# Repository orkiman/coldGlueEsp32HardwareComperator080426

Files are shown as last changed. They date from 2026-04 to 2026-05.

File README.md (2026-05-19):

# Cold Glue Controller — Main Controller Firmware (Stage 1)

ESP32-S3-WROOM-1-N16R8 firmware for a 4-channel high-speed cold-glue gun
controller. Up to 330 Hz droplet rate; current chopping is handled by the
on-board LM339 hardware loop. The ESP32 only orchestrates phase transitions.

See `docs/initial prompt.md` for the full hardware architecture and operational
spec.

## Toolchain

PlatformIO (recommended). Open the project folder in VS Code with the
PlatformIO extension and use `PlatformIO: Upload` / `Monitor`.

```
pio run -t upload
pio device monitor
```

## Source Tree

```
src/
  main.cpp                          task wiring + boot order
  config/Config.{h,cpp}             double-buffered config + pattern storage
  comms/
    Events.{h,cpp}                  Core1->Core0 lock-free event queue
    UartJson.{h,cpp}                NDJSON parser + command dispatcher
  hw/
    Pins.h                          pin map (verbatim from docs)
    Driver.{h,cpp}                  IN1/IN2/MUX_SELECT abstraction, killAll
    Dac.{h,cpp}                     MCP4728 with task-serialized I2C writes
    Encoder.{h,cpp}                 PCNT counter + photocell ISR (any-edge)
  rt/
    GunSequencer.{h,cpp}            per-gun Peak/Hold/Decay state machine
    PatternScheduler.{h,cpp}        sheet FIFO + lazy pattern walker
    Control.{h,cpp}                 surface called by JSON dispatcher
  sys/
    Fault.{h,cpp}                   nFAULT ISR -> master kill
    Watchdog.{h,cpp}                HMI link timeout
    Status.{h,cpp}                  5 Hz status emitter
```

## Task Layout

| Core | Task | Prio | Purpose |
| ---- | --- | ---- | --- |
| 0 | `uart_rx` | 4 | NDJSON parser |
| 0 | `evt_emit`  | 5 | Drains event queue to Serial |
| 0 | `wdog` | 3 | HMI link watchdog |
| 0 | `status` | 2 | 5 Hz `{"event":"status"}` |
| 1 | `pattern` | 7 | Encoder poll + fire pattern events |
| 1 | `dac` | 6 | Coalesced MCP4728 I2C writes |
| 1 | ISRs | IRAM | Peak (x4), photocell, nFAULT, PCNT |

## Protocol

Newline-delimited JSON over UART0 (115200 8N1) on GPIO 43 TX / GPIO 44 RX,
routed through the on-board CP2102 USB-UART for development.

Commands and events follow `docs/initial prompt.md` Section 8 exactly.

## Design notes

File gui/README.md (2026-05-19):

# Cold Glue Controller — PC GUI

Operator interface for the ESP32-S3 cold glue controller. Talks NDJSON
over USB serial (CP2102 @ 115200) to the firmware in `../src/`.

## Stack

- Python 3.11+
- PySide6 (Qt 6) — RTL Hebrew UI, QGraphicsView pattern editor
- pyserial — serial transport

## Install

```powershell
python -m venv .venv
.\.venv\Scripts\Activate.ps1
pip install -r requirements.txt
```

## Run

```powershell
python run.py            # real serial
python run.py --mock     # in-process fake firmware, no hardware needed
```

## Packaging (later)

```powershell
pyinstaller --noconsole --onefile run.py -n GlueController
```

## Layout

```
gui/
  run.py                       entry point
  app/
    protocol.py                NDJSON command builders + event parsing
    link_base.py               abstract link (Qt signals)
    serial_link.py             pyserial implementation
    mock_link.py               in-process fake firmware
    state.py                   central app state (config, patterns, status)
    profiles.py                save/load profile JSONs
  ui/
    theme.py                   palette + QSS loader
    styles.qss                 dark industrial theme
    main_window.py             shell with sidebar nav
    widgets/
      connection_bar.py        COM picker + status LED + ping
      numeric_field.py         labelled spinbox with units
      pattern_editor.py        QGraphicsView pattern canvas (TBD)
    screens/
      operate.py               start/stop, live status
      patterns.py              visual pattern editor host
      configure.py             per-gun currents + hold time
      admin.py                 calibration, globals, event log
```

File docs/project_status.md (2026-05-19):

# Cold Glue Controller — Project Status

> Living document. Reflects what is **actually implemented** in firmware.
> The original spec lives in `initial prompt.md` and should not be edited;
> this file records any decisions, deltas, and the current state.

Last updated: Stage 2 GUI scaffold (PySide6) in progress; per-gun
`on_timeout_ms` (renamed from `hold_time_ms`, semantics changed to
"start-of-cycle timer") landed in both firmware and GUI.

---

## 1. Stage Status

| Stage | Scope | Status |
| ----- | --- | --- |
| 1 | ESP32-S3 main controller firmware | **Code complete** — pending hardware bring-up |
| 2 | PC-side GUI over UART0 (PySide6) | **In progress** — `gui/` tree; mock-link works, real-link path implemented |

The original Stage 2 plan was an LVGL HMI on a second ESP32-S3 + 7" touch
panel. **Revised decision:** for now the operator UI runs on a PC and talks
to the main controller through the on-board CP2102 USB-UART. The wire
protocol (NDJSON over UART0 @ 115200) is identical, so swapping back to an
embedded HMI later is a drop-in.

---

## 2. Implemented Architecture

### Dual-core task layout

| Core | Task | Prio | File | Purpose |
| ---- | --- | ---- | --- | --- |
| 0 | `uart_rx` | 4 | `comms/UartJson.cpp` | NDJSON parser + command dispatcher |
| 0 | `evt_emit`  | 5 | `comms/Events.cpp` | Drains lock-free event queue -> Serial |
| 0 | `wdog` | 3 | `sys/Watchdog.cpp` | HMI link timeout (2 s) |
| 0 | `status` | 2 | `sys/Status.cpp` | 5 Hz `{"event":"status"}` |
| 1 | `pattern` | 7 | `rt/PatternScheduler.cpp` | Encoder poll + fire pattern events |
| 1 | `dac` | 6 | `hw/Dac.cpp` | Coalesced MCP4728 I2C writes |
| 1 | ISRs | IRAM | `hw/Encoder`, `rt/GunSequencer`, `sys/Fault` | Peak (x4), photocell, nFAULT, PCNT overflow |

### Key isolation rules (enforced by file layout)

- Only `evt_emit` task ever touches `Serial`. No other module may print.
- ISRs never block on I2C: DAC writes are queued to the Core-1 `dac` task.
- Config is published via atomic double-buffer pointer swap; hot path reads
  are lock-free.
- Cross-core events use FreeRTOS queues with `*FromISR` APIs.

---

## 3. Dot Sequence — Implementation Map

| Phase | Trigger | File / function |
| --- | --- | --- |
| 1 Peak / Pick | `seq::fire(g)` | `rt/GunSequencer.cpp :: fire()` |
| 2 Hold (chopping) | LM339 peak IRQ | `rt/GunSequencer.cpp :: peakIsr()` |
| 3 Active Fast Decay  | on-timer expiry OR `seq::abort()`| `rt/GunSequencer.cpp :: onTimerCb() / abort()` |

Per-gun state machine is `Idle -> Peak -> Hold -> Decay -> Idle`, guarded
by a `compare_exchange_strong` so `fire()` is safe from any context.

### On-timer (Peak+Hold budget)

`fire()` arms a single `esp_timer` (`onTimer`, per gun) for the full
per-gun `on_timeout_ms` budget, starting **at the moment of fire()**, not
at the LM339 peak trip.  This means:

- Normal flow: LM339 -> `peakIsr` -> Hold phase; the same timer keeps
  counting and forces Phase 3 when the budget expires.
- Fault flow: if the peak trip never arrives (open coil, broken sense,
  wrong threshold), the same timer still fires, drops the gun into
  Phase 3, and masks the late IRQ defensively.  No more "stuck in Peak"
  failure mode.
- `seq::abort(g)` stops the on-timer and force-enters Phase 3 (used by
  Lines to terminate at the encoder-position end of the line).

---

## 4. Pattern Execution

- Per-gun **sheet FIFO depth = 4** (`SHEET_QUEUE_DEPTH` in `PatternScheduler.cpp`).
- Sheet entries store only the encoder pulse count at the photocell leading
  edge. Patterns are walked **lazily** at runtime — dots are not pre-expanded.
- Pattern coordinate origin = paper leading edge =
  `photocell pulse + photocell_offset_mm * pulses_per_mm`.
- If gap between sheets < `photocell_offset_mm`, multiple sheets are tracked
  in flight on the same gun. Queue overflow drops the new trigger silently.
- Speed-safety: if measured speed drops below `min_speed_mm_s`, the pattern
  task suppresses firing until speed recovers.

---

## 5. Diagnostic `test_open` Behaviour (revised)

`test_open` no longer issues a single raw dot. Behaviour depends on the gun's
currently configured pattern type (see `rt/TestRunner.cpp`):

| Pattern type | Test behaviour |
| --- | --- |
| `lines` | Single line, hardware-regulated, held for `timeout_ms`, then Phase 3 |
| `dots` | Continuous dot train at 20 Hz until `timeout_ms` or `test_close` |
| `none` | `{"event":"error","cmd":"test_open","reason":"no_pattern_or_busy"}`  |

`gun:0` broadcasts the test to every gun with a configured pattern.
`timeout_ms` is capped at 5000 in `UartJson::handleTestOpen`.

---

## 6. Fault & Safety Path

- **nFAULT (GPIO 39, active LOW)**: IRAM ISR in `sys/Fault.cpp` immediately
  calls `drv::killAll()`, aborts all gun sequencers, sets
  `g_sys.fault = true`, `g_sys.active = false`, and emits
  `{"event":"error","reason":"hardware_fault"}`.
- Recovery requires a fresh `set_active:true` from the operator.
- **Watchdog**: any received NDJSON command (incl. `ping`) refreshes the
  timestamp. After 2 s of silence while active, outputs are killed and
  `{"event":"watchdog_timeout"}` is emitted.

---

## 7. Protocol — Deltas From `initial prompt.md` §8

### 7.1 New error reason

| Where | Reason | Meaning |
| --- | --- | --- |
| `test_open` | `no_pattern_or_busy` | Gun has no pattern, or a test is already running on it. |
| `set_pattern`  | `bad_on_timeout` | `on_timeout_ms` was supplied but ≤ 0. |

All other validation errors (`bad_pulses_per_mm`, `hold_ge_pick`, etc.) are
sanity checks in `set_config` / `set_pattern`.

### 7.2 `on_timeout_ms` — per-gun, start-of-cycle

Previously a global `hold_time_ms` in `RuntimeConfig` was started by
`peakIsr` and counted only the Hold phase.  It has been replaced by a
per-gun `on_timeout_ms` inside `GunPattern`, started by `fire()` itself
and counting the **entire** Peak+Hold budget.

- `set_config` **no longer accepts** any droplet-timing field.
- `set_pattern` accepts a top-level optional `on_timeout_ms` (ms, float).
  Absent → preserve previous per-gun value (`editScratch()` copies the
  active buffer).
- Default per-gun value at boot: **1.2 ms**.
- **Dots mode**: `on_timeout_ms` is the user-facing droplet on-time.
- **Lines mode**: `on_timeout_ms` is used only as a long safety ceiling
  (`seq::fire(g, 5000)` is hard-capped to 5 s inside `fire()`).  Line
  termination is encoder-position driven (`seq::abort(g)` at `end_mm`,
  see `PatternScheduler::patternTask`).  Speed-safety (`min_speed_mm_s`)
  still suppresses firing entirely.
- **No more "stuck in Peak"**: because the on-timer starts at `fire()`,
  a missing LM339 trip cannot pin IN1 HIGH indefinitely.

Example payload:

```json
{ "cmd": "set_pattern", "gun": 2, "type": "dots",
  "on_timeout_ms": 1.8,
  "elements": [ {"start": 60, "end": 240, "spacing": 5} ] }
```

---

## 8. Open Items For Bench Bring-Up

- **`Adafruit_MCP4728::fastWrite` signature** — assumed `(uint16_t, uint16_t, uint16_t, uint16_t)` returning `bool`; will fail at compile if the installed lib differs.
- **PCNT glitch filter** at 100 APB ticks (~1.25 µs). Will tune once we see the 6N137's real edge behaviour on the scope.
- **`NEAR_ZERO_V = 0.10 V`** Phase-3 termination threshold. Tunable in `rt/GunSequencer.cpp`. Right now corresponds to ~0.05 A coil current.
- **On-timer dispatch via `esp_timer` task context** (not ISR). Worst-case latency ~50 µs; fine for on-times ≥ 1 ms but introduces jitter if `on_timeout_ms` is set absurdly small.
- **No `error` event yet for the "peak trip never arrived" case** — the
  on-timer correctly drops the gun into Phase 3 (no stuck-in-Peak any
  more), but we still can't tell from outside whether a given fire cycle
  passed through `peakIsr` or hit the on-timeout without it.  *Future:*
  emit a diagnostic event from `onTimerCb` if the gun was still in
  `Phase::Peak` when the timer expired.

---

## 9. File Tree (current)

```
platformio.ini
README.md
docs/
  initial prompt.md            (immutable spec — do not edit)
  project_status.md            (this file)
src/                           (ESP32-S3 firmware)
  main.cpp
  config/Config.{h,cpp}
  comms/Events.{h,cpp}    UartJson.{h,cpp}
  hw/Pins.h               Driver.{h,cpp}   Dac.{h,cpp}   Encoder.{h,cpp}
  rt/Control.{h,cpp}      GunSequencer.{h,cpp}   PatternScheduler.{h,cpp}   TestRunner.{h,cpp}
  sys/Fault.{h,cpp}       Watchdog.{h,cpp}       Status.{h,cpp}
gui/                           (PySide6 operator UI)
  run.py                       Launcher (`--mock` for offline dev)
  requirements.txt
  app/
    protocol.py                NDJSON command builders + enums
    link_base.py               Abstract link (Qt signals)
    mock_link.py               In-process simulator
    serial_link.py             pyserial-backed real transport
    state.py                   AppState — single source of truth
    profiles.py                Save/load full operator profile (JSON)
  ui/
    main_window.py             Sidebar (הפעלה / תוכנית / הגדרות) + menu
    styles.qss                 Dark theme
    screens/operate.py         Run-time controls + live status
    screens/patterns.py        Per-gun toolbar + visual editor (4 lanes)
    screens/configure.py       Currents, globals, calibration, event log
    widgets/connection_bar.py  COM picker / Connect / Active / E-stop
    widgets/numeric_field.py   Debounced labelled spinbox
    widgets/pattern_editor.py  QGraphicsScene-based segment editor
```

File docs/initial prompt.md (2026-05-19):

**User Instruction:** Copy and paste this entire document into a new AI chat to instantly bring the AI up to speed on your project.

# System Prompt for AI: Cold Glue Gun Controller Firmware

Act as an expert Embedded C++ Firmware Engineer and Industrial Electronics Specialist. I am developing firmware for a custom "Cold Glue Controller" PCB used in high-speed industrial manufacturing (up to 330Hz droplet rate).
The hardware design is complete and validated. **Do not suggest altering the core hardware architecture.** Your job is to help me write, optimize, and debug the C++ firmware for the ESP32-S3 using the Arduino IDE / PlatformIO framework.

Please read the following hardware context and operational logic carefully before writing any code.

## 1. Project Context & Core Architecture

* **Microcontroller (Main Controller):** `YD-ESP32-S3` compatible board (specifically `ESP32-S3-WROOM-1-N16R8` with 16MB Flash, 8MB PSRAM). Strictly 3.3V logic.

* **Power Systems:** * **High Power:** 48VDC (for solenoids), with reverse polarity protection and bulk capacitors for absorbing regenerative currents.

  * **Logic Power:** 24VDC stepped down to 5V (via K7805 switching regulator), and then to 3.3V via the ESP32 internal regulator.

* **Outputs:** 4 independent high-speed cold glue guns (solenoids).

* **Control Method (Hybrid Hardware/Software):** To prevent the ESP32 from crashing due to high-frequency interrupt storms, the board uses a **hardware-assist handoff** (Hardware Sense Loop) to manage the solenoid current chopping (PWM). The ESP32 acts as the orchestrator.

## 2. Bill of Materials (Core Actuation Components)

* **Motor Drivers:** 2x `DRV8262` (One chip per 2 guns). Configured in independent PWM Mode (`MODE1` & `MODE2` = GND, `nSLEEP` = HIGH).

  * *Truth Table:* `IN1=1, IN2=0` (Forward); `IN1=1, IN2=1` (Slow Decay/Brake); `IN1=0, IN2=1` (Reverse); `IN1=0, IN2=0` (Coast/Fast Decay).

* **Current Sense:** 4x `INA240A2DR`. Fixed gain of 50 V/V, measuring across 40mΩ shunts.

  * *Formula:* Vout = I_amps * 0.04Ω * 50 = I_amps * 2 (e.g., 1.0A = 2.0V, 0.4A = 0.8V).

* **DAC:** 1x `MCP4728` (I2C, 3.3V). Sets the dynamic reference voltage (thresholds) for the comparators.

* **Hardware Comparators:** 1x `LM339` Quad Comparator (5V power, 10k pull-ups to 3.3V on outputs). Compares INA240 output against the DAC threshold.

* **Hardware MUX:** 4x `74LVC1G157` (3.3V). Routes signals to the DRV8262 `IN2` pin.

  * *MUX Logic:* `Select (S) = 0` routes `I0` (Manual control from ESP32). `Select (S) = 1` routes `I1` (Hardware control from LM339 comparator).

## 3. The "Dot Sequence" (Master Operational Logic)

This sequence defines how the ESP32 interacts with the hardware loop to fire a single dot of glue.

### Phase 1: Peak / Pick Phase (Fast Opening)

* **Goal:** Dump maximum current to open the solenoid instantly.

* **Action:** 1. ESP32 dynamically calculates and sets the DAC channel to the peak threshold (e.g., **2.0V** for 1.0A).
  2. ESP32 drives driver `IN1 = HIGH`.
  3. ESP32 pulls `MUX_SELECT = HIGH` (S=1), arming the hardware loop by routing the LM339 directly to `IN2`.

* **Hardware Response:** Current ramps up. When it hits 1A, the LM339 goes HIGH, switching `IN2` HIGH via the MUX. Driver enters Slow Decay/Brake mode (`IN1=1, IN2=1`). An interrupt is fired to the ESP32.

### Phase 2: Hold Phase (Hardware Chopping)

* **Goal:** Keep the solenoid open without overheating.

* **Action:**

  1. The peak interrupt (`GunXInterrupt`) triggers the ISR on the ESP32.

  2. **ISR Action:** ESP32 immediately updates the DAC to the hold threshold (e.g., **0.8V** for 0.4A).

  3. **ISR Action:** ESP32 starts a hardware timer for the desired hold duration (Thold, typically ~1ms).

  4. **ISR Action:** ESP32 *disables* the external interrupt for this pin to avoid being flooded by the chopping signals.

* **Hardware Response:** The LM339 now autonomously bang-bangs `IN2` HIGH/LOW to maintain exactly 0.4A. The ESP32 does nothing during this time.

### Phase 3: Active Fast Decay (Rapid Closing)

* **Goal:** Kill the magnetic field instantly using -48V, switching off right before current flows backward to prevent heating the internal diodes.

* **Action:**

  1. The Thold timer expires.

  2. ESP32 updates the DAC to a near-zero threshold (e.g., **0.1V** for ~0.05A).

  3. ESP32 immediately pulls `IN1 = LOW` (leaving `MUX_SELECT = HIGH`).

* **Hardware Response:** Since the current (0.4A) is above the new near-zero threshold, the LM339 keeps `IN2 = HIGH`. The driver enters **Reverse Drive** (`IN1=0, IN2=1`), slamming -48V across the coil.

* **The Magic:** The moment the current collapses and hits the 0.05A threshold (fractions of a millisecond later), the LM339 drops `IN2 = LOW`. The driver enters Coast mode (`IN1=0, IN2=0`), safely terminating the cycle without reverse current.

## 4. ESP32-S3 Pin Assignment Map

| **Function** | **Gun 1** | **Gun 2** | **Gun 3** | **Gun 4** | **Notes** | 
| ----- | ----- | ----- | ----- | ----- | ----- |
| **Opto Input (24V)** | GPIO 1 | GPIO 2 | GPIO 4 | GPIO 5 | TLP291-4 Optocouplers | 
| **IN1 (Main Drive)** | GPIO 6 | GPIO 7 | GPIO 15 | GPIO 16 | Direct to DRV8262 `IN1`/`IN3` | 
| **IN2 (Manual MUX I0)** | GPIO 8 | GPIO 9 | GPIO 17 | GPIO 18 | MUX `I0` input (Used for manual ESP32 override if needed) | 
| **MUX Select (S)** | GPIO 10 | GPIO 11 | GPIO 14 | **GPIO 48** | HIGH=LM339 Control, LOW=ESP32 Control. *(GPIO 48 shares RGB LED)* | 
| **Peak Interrupt** | GPIO 12 | GPIO 13 | GPIO 21 | GPIO 38 | From LM339 (has external 10k pull-ups) | 

**Global Pins:**

* `I2C_SDA`: **GPIO 41** (To MCP4728)

* `I2C_SCL`: **GPIO 42** (To MCP4728)

* `nFAULT`: **GPIO 39** (From DRV8262. Has external 10k pull-up. Active LOW).

* `ENCODER`: **GPIO 40** (High-speed input via 6N137 optocoupler).

## 5. Software Architecture & Dual-Core Strategy

To maintain real-time deterministic performance for the 330Hz droplet rate, the firmware MUST utilize FreeRTOS and the ESP32's dual cores:

* **Core 1 (Real-Time Hardware Core):** Dedicated exclusively to hardware operations. Handles the high-speed encoder pulses, manages the "Dot Sequence" state machine, responds to LM339 interrupts, updates the DAC, and drives the MUX/Drivers. No blocking code allowed.

* **Core 0 (Management & Comms Core):** Dedicated to administrative tasks. Listens on UART (Serial) for JSON command updates from the external HMI screen, and updates the shared memory variables safely.

## 6. Glue Pattern & Operational Features

The software logic must implement the following operational features:

* **Position & Timing (Hybrid):** Gun start positions are triggered by Encoder distance calculations (pulses per mm). Droplet duration (valve open time) is controlled by a hardware timer.

* **Trigger:** One of the 24V inputs (e.g., `Input_1_24v`) will act as the single photocell trigger to initiate the pattern sequence for the current sheet. Only one sheet is tracked at a time.

* **Pattern Types:** Each gun can be configured independently to shoot:

  * **Lines:** Defined by `start_mm` and `end_mm`.

  * **Dots:** Defined by `start_mm`, `end_mm`, and `dot_spacing_mm`.

* **Safety & Protections:** Implement a speed monitor to disable gluing if the encoder speed drops below a minimum threshold, and a Watchdog timer to shutdown all drivers if communication with the HMI is lost.

## 7. External HMI & Communication (For AI Context)

* **HMI Hardware:** A separate ESP32-S3 development panel with a 7-inch capacitive touch screen (800x480) and 8MB PSRAM.

* **GUI Framework:** LVGL (C/C++) handling all graphical rendering.

* **Communication:** The HMI acts as the master UI. It communicates with the Main Controller via simple UART (Serial RX/TX @ 115200 baud).

## 8. Communication Protocol (NDJSON)

The communication uses Newline Delimited JSON (NDJSON) via UART. Core 0 must parse these commands and respond accordingly.

**Commands (HMI -> Main Controller):**

* `set_active`: `{"cmd":"set_active","active":true}`

* `set_config`: `{"cmd":"set_config","pulses_per_mm":12.34,"min_speed_mm_s":100,"photocell_offset_mm":250.0,"debounce_ms":20,"pick_current_a":1.0,"hold_current_a":0.4,"hold_time_ms":1.2}` *(Note: Main controller calculates DAC voltage from the Current 'A' values).*

* `set_pattern` (Lines): `{"cmd":"set_pattern","gun":1,"type":"lines","elements":[{"start":10,"end":40}]}`

* `set_pattern` (Dots): `{"cmd":"set_pattern","gun":2,"type":"dots","elements":[{"start":10,"end":50,"spacing":5}]}`

* `calib_arm`: `{"cmd":"calib_arm","paper_length_mm":297.0}`

* `test_open`: `{"cmd":"test_open","gun":1,"timeout_ms":2000}` *(gun: 1, 2, 3, 4, or 0 for "all")*

* `test_close`: `{"cmd":"test_close","gun":1}`

* `ping`: `{"cmd":"ping"}` *(Used for Watchdog timeout reset)*

* `sw_trigger`: `{"cmd":"sw_trigger"}` *(Manual photocell simulation)*

**Events (Main Controller -> HMI):**

* `ready`: `{"event":"ready"}`

* `ack`: `{"event":"ack","cmd":"set_active"}`

* `error`: `{"event":"error","cmd":"set_pattern","reason":"invalid_gun"}`

* `calib_result`: `{"event":"calib_result","pulses_per_mm":12.34}`

* `status`: `{"event":"status","pos_mm":150.5,"speed_mm_s":1200,"active":true}` *(Sent periodically, e.g., 5Hz, to prevent UART flooding from raw encoder ticks).*

* `watchdog_timeout`: `{"event":"watchdog_timeout"}`

## 9. Development Roadmap

We will develop this project in two distinct stages:

* **Stage 1: The Core ESP Firmware (Main Controller).** We will focus entirely on the FreeRTOS architecture, hardware interaction (DAC, MUX, Drivers), the dot sequence state machine, encoder handling, and JSON UART parsing.

* **Stage 2: The Control Program (GUI).** Once the main controller is fully functional and tested via UART commands, we will move on to developing the LVGL-based HMI on the secondary screen. Do not write any GUI code during Stage 1.

**Initial Task:** Acknowledge you have read and understood this architecture and the development stages. Do not write the full code yet. Briefly explain your plan for structuring the FreeRTOS tasks across the two cores for **Stage 1**, and how you will handle the UART JSON parsing without blocking the 330Hz hardware loop.

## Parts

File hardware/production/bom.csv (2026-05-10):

Designator | Footprint | Quantity | Value | LCSC Part #
C1, C2 | CAP-TH_BD16.0-P7.50-D0.8-FD | 2 | LKMI2001K681MF_C42404588 | C507603
C10, C11, C12, C13, C14, C15, C18, C19, C20, C21, C22, C23, C6 | 0603 | 13 | 100nf 50v | C14663
C16 | 1206 | 1 | 10uf 50v | C13585
C17 | 1206 | 1 | 22uf 25v | C12891
C3, C5, C7, C9 | 0603 | 4 | 1uf 50v | C15849
C4, C8 | 0805 | 2 | 100nf 100v | C28233
CN1, CN2, CN3, CN4, CN5, CN6, CN7 | CONN-TH_P5.00_KF243-5.0-2P | 7 | KF243-5.0-2P | C475222
CN9 | CONN-TH_4P-P5.00_KF243-5.0-4P | 1 | KF243-5.0-4P | C475224
D1, D14 | D_SMA | 2 | SS14 | C2480
D10, D2, D3, D4, D5 | 0805 | 5 | green | C2297
D11 | D_SMA | 1 | SS26 | C14238
D12 | D_SOD-123 | 1 | BZT52C15 zener | C2104
D13 | D_SMC | 1 | SMCJ51A | C438115
D15 | 0805 | 1 | yellow power ON | C2296
D6, D7, D8, D9 | 0805 | 4 | red | C84256
J1, J3 | PinSocket_1x22_P2.54mm_Vertical | 2 | Female Header 1x22 | C7499337
Q1 | TO-263-2 | 1 | SQM120P10-10m1L | C3281565
R1, R10, R2, R21, R22, R23 | 0603 | 6 | 10k | C25804
R11 | 0603 | 1 | 100r | C22775
R12, R13, R15, R16 | 1206 | 4 | 4.7k | C17936
R14 | 0603 | 1 | 1k | C21190
R17, R18, R19, R20 | 2512 | 4 | 40m | C459685
R3, R4, R5, R6 | 0603 | 4 | 5.1k | C23186
R7 | 0805 | 1 | 33k | C17633
R8 | 0805 | 1 | 100k | C25611
R9 | 0603 | 1 | 470r | C23179
RN1 | R_Array_Convex_4x0603 | 1 | 470r | C354986
RN2 | R_Array_Convex_4x0603 | 1 | 10k | C107374
U1, U2 | HTSSOP44-DDW_TEX | 2 | DRV8262DDWR | C22427252
U10, U11, U6, U7 | SOIC-8_L4.9-W3.9-P1.27-LS6.0-BL | 4 | INA240A2DR | C2060768
U12 | SOIC-14_3.9x8.7mm_P1.27mm | 1 | LM339 | C7948
U13, U14, U15, U16 | TSOP-6_L3.0-W1.5-P0.95-LS2.8-BR | 4 | 74LVC1G157GV,125 | C503437
U4 | MSOP-10_3x3mm_P0.5mm | 1 | MCP4728 | C478093
U5 | SMDIP-8_W9.53mm | 1 | 6N137 | C16496
U8 | PWRM-TH_YLPTEC_K78XX-1000R3 | 1 | K7805-1000R3_C2992391 | C2992391
U9 | SOP-16_L10.3-W4.4-P1.27-LS7.0-BL | 1 | TLP291-4(V4GBTPE) | C2848503

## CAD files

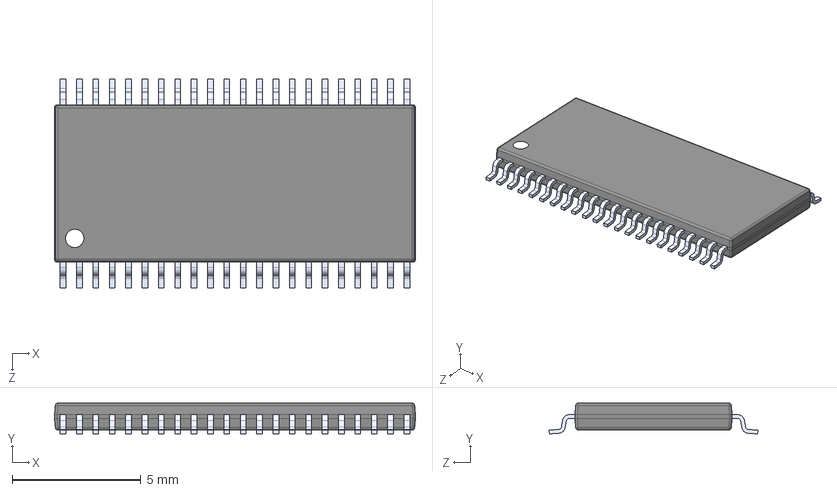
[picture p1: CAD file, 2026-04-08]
hardware/myLibs/DRV8262DDWR/DRV8262DDWR.step
14.0 x 1.20 x 8.10 mm

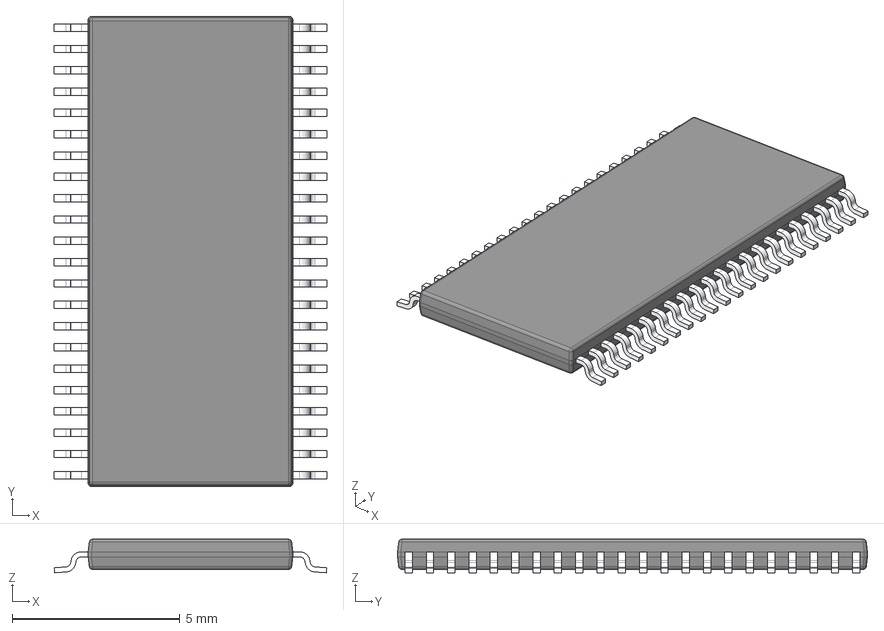
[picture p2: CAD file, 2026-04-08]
hardware/myLibs/ul_DRV8262DDWR (1)/DDW0044E.stp
8.12 x 14.0 x 1.00 mm
BODY-SO
LEAD-SO x 44
THERMALPAD-SO

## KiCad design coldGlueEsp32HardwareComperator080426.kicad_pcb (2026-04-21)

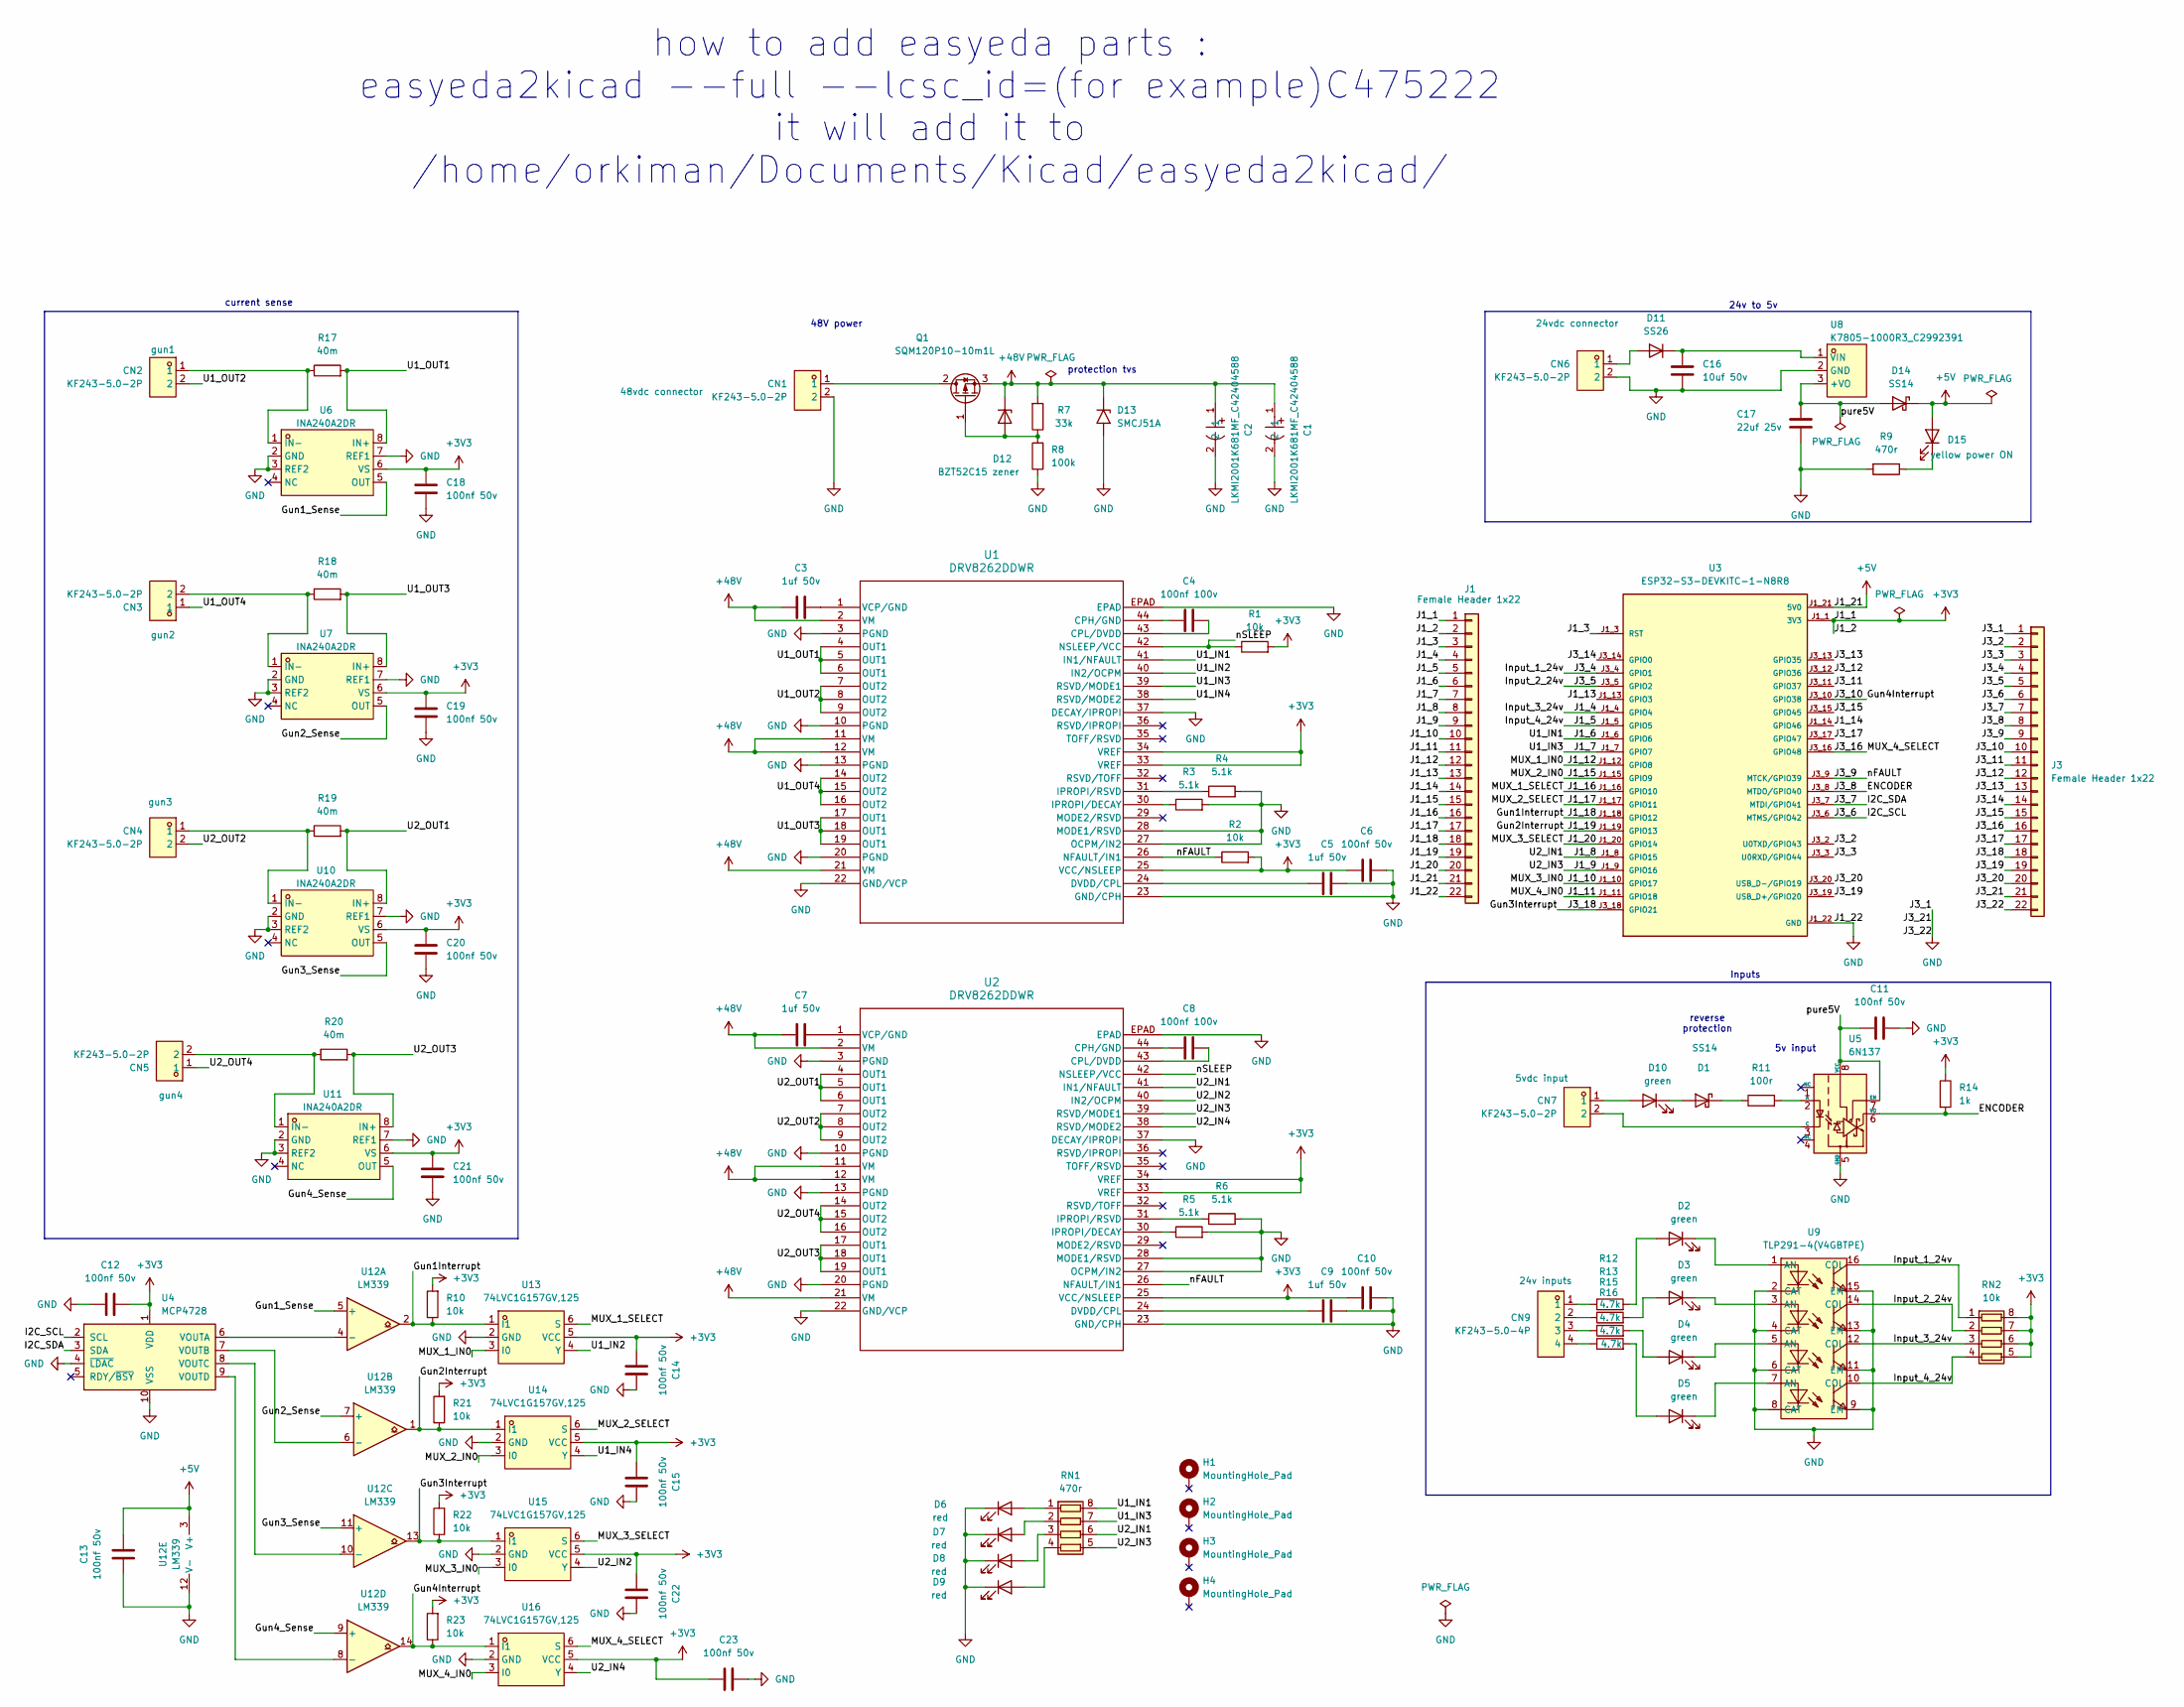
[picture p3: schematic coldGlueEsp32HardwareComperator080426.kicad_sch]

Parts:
C1, C2: LKMI2001K681MF_C42404588; CAP-TH_BD16.0-P7.50-D0.8-FD; LCSC_ALT C507603
C3, C5, C7, C9: 1uf 50v; C_0603_1608Metric; LCSC C15849
C4, C8: 100nf 100v; C_0805_2012Metric; LCSC C28233
C6, C10, C11, C12, C13, C14, C15, C18, C19, C20, C21, C22, C23: 100nf 50v; C_0603_1608Metric; LCSC C14663
C16: 10uf 50v; C_1206_3216Metric; LCSC C13585
C17: 22uf 25v; C_1206_3216Metric; LCSC C12891
CN1, CN2, CN3, CN4, CN5, CN6, CN7: KF243-5.0-2P; CONN-TH_P5.00_KF243-5.0-2P; LCSC C475222
CN9: KF243-5.0-4P; CONN-TH_4P-P5.00_KF243-5.0-4P; LCSC C475224
D1: SS14; D_SMA; part ss14; LCSC C2480
D2, D3, D4, D5, D10: green; LED_0805_2012Metric; LCSC C2297
D6, D7, D8, D9: red; LED_0805_2012Metric; LCSC C84256
D11: SS26; D_SMA; part ss26; LCSC C14238
D12: BZT52C15 zener; D_SOD-123; LCSC C2104
D13: SMCJ51A; D_SMC; LCSC C438115
D14: SS14; D_SMA; LCSC C2480
D15: yellow power ON; LED_0805_2012Metric; LCSC C2296
H1, H2, H3, H4: MountingHole_Pad; MountingHole_3.2mm_M3_Pad
J1, J3: Female Header 1x22; PinSocket_1x22_P2.54mm_Vertical; LCSC_ALT C47940(40p)
Q1: SQM120P10-10m1L; TO-263-2; LCSC_ALT C468007
R1, R2, R10, R21, R22, R23: 10k; R_0603_1608Metric; LCSC C25804
R3, R4, R5, R6: 5.1k; R_0603_1608Metric; LCSC C23186
R7: 33k; R_0805_2012Metric; LCSC C17633
R8: 100k; R_0805_2012Metric; LCSC C25611
R9: 470r; R_0603_1608Metric; LCSC C23179
R11: 100r; R_0603_1608Metric; LCSC C22775
R12, R13, R15, R16: 4.7k; R_1206_3216Metric; LCSC C17936
R14: 1k; R_0603_1608Metric; LCSC C21190
R17, R18, R19, R20: 40m; R_2512_6332Metric; LCSC C459685
RN1: 470r; R_Array_Convex_4x0603; LCSC_ALT C25510
RN2: 10k; R_Array_Convex_4x0603; LCSC_ALT C29718
U1, U2: DRV8262DDWR; HTSSOP44-DDW_TEX; LCSC C22427252
U3: ESP32-S3-DEVKITC-1-N8R8; XCVR_ESP32-S3-DEVKITC-1-N8R2; PARTREV V1
U4: MCP4728; MSOP-10_3x3mm_P0.5mm; LCSC C478093
U5: 6N137; SMDIP-8_W9.53mm; LCSC C16496
U6, U7, U10, U11: INA240A2DR; SOIC-8_L4.9-W3.9-P1.27-LS6.0-BL; LCSC C2060768
U8: K7805-1000R3_C2992391; PWRM-TH_YLPTEC_K78XX-1000R3; LCSC C2992391
U9: TLP291-4(V4GBTPE); SOP-16_L10.3-W4.4-P1.27-LS7.0-BL; LCSC C2848503
U12: LM339; SOIC-14_3.9x8.7mm_P1.27mm; LCSC C7948
U13, U14, U15, U16: 74LVC1G157GV,125; TSOP-6_L3.0-W1.5-P0.95-LS2.8-BR; MPN 74LVC1G157GV,125; LCSC C503437

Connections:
+3V3: C6.1, C10.1, C12.2, C14.1, C15.1, C18.1, C19.1, C20.1, C21.1, C22.1, C23.1, J1.1, J1.2, R1.2, R2.2, R10.2, R14.1, R21.2, R22.2, R23.2, RN2.5 (R4.2), RN2.6 (R3.2), RN2.7 (R2.2), RN2.8 (R1.2), U1.25 (VCC/NSLEEP), U1.33 (VREF), U1.34 (VREF), U2.25 (VCC/NSLEEP), U2.33 (VREF), U2.34 (VREF), U3.J1_1 (3V3), U3.J1_2 (3V3), U4.1 (VDD), U6.6 (VS), U7.6 (VS), U10.6 (VS), U11.6 (VS), U13.5 (VCC), U14.5 (VCC), U15.5 (VCC), U16.5 (VCC)
+5V: C13.2, D14.1 (K), D15.2 (A), J1.21, U3.J1_21 (5V0), U12.3 (V+)
+48V: C1.1, C2.1, C3.1, C7.1, D12.1 (K), D13.1 (A1), Q1.3 (S), R7.2, U1.2 (VM), U1.11 (VM), U1.12 (VM), U1.21 (VM), U2.2 (VM), U2.11 (VM), U2.12 (VM), U2.21 (VM)
/ENCODER: J3.8, R14.2, U3.J3_8 (MTDO/GPIO40), U5.6 (VO)
/Gun1Interrupt: J1.18, R10.1, U3.J1_18 (GPIO12), U12.2, U13.1 (I1)
/Gun1_Sense: U6.5 (OUT), U12.5 (+)
/Gun2Interrupt: J1.19, R21.1, U3.J1_19 (GPIO13), U12.1, U14.1 (I1)
/Gun2_Sense: U7.5 (OUT), U12.7 (+)
/Gun3Interrupt: J3.18, R22.1, U3.J3_18 (GPIO21), U12.13, U15.1 (I1)
/Gun3_Sense: U10.5 (OUT), U12.11 (+)
/Gun4Interrupt: J3.10, R23.1, U3.J3_10 (GPIO38), U12.14, U16.1 (I1)
/Gun4_Sense: U11.5 (OUT), U12.9 (+)
/I2C_SCL: J3.6, U3.J3_6 (MTMS/GPIO42), U4.2 (SCL)
/I2C_SDA: J3.7, U3.J3_7 (MTDI/GPIO41), U4.3 (SDA)
/Input_1_24v: J3.4, RN2.1 (R1.1), U3.J3_4 (GPIO1), U9.16 (COL)
/Input_2_24v: J3.5, RN2.2 (R2.1), U3.J3_5 (GPIO2), U9.14 (COL)
/Input_3_24v: J1.4, RN2.3 (R3.1), U3.J1_4 (GPIO4), U9.12 (COL)
/Input_4_24v: J1.5, RN2.4 (R4.1), U3.J1_5 (GPIO5), U9.10 (COL)
/J1_3: J1.3, U3.J1_3 (RST)
/J1_6: J1.6, RN1.8 (R1.2), U1.41 (IN1/NFAULT), U3.J1_6 (GPIO6)
/J1_7: J1.7, RN1.7 (R2.2), U1.39 (RSVD/MODE1), U3.J1_7 (GPIO7)
/J1_8: J1.8, RN1.6 (R3.2), U2.41 (IN1/NFAULT), U3.J1_8 (GPIO15)
/J1_9: J1.9, RN1.5 (R4.2), U2.39 (RSVD/MODE1), U3.J1_9 (GPIO16)
/J1_10: J1.10, U3.J1_10 (GPIO17), U15.3 (I0)
/J1_11: J1.11, U3.J1_11 (GPIO18), U16.3 (I0)
/J1_12: J1.12, U3.J1_12 (GPIO8), U13.3 (I0)
/J1_13: J1.13, U3.J1_13 (GPIO3)
/J1_14: J1.14, U3.J1_14 (GPIO46)
/J1_15: J1.15, U3.J1_15 (GPIO9), U14.3 (I0)
/J1_16: J1.16, U3.J1_16 (GPIO10), U13.6 (S)
/J1_17: J1.17, U3.J1_17 (GPIO11), U14.6 (S)
/J1_20: J1.20, U3.J1_20 (GPIO14), U15.6 (S)
/J3_2: J3.2, U3.J3_2 (U0TXD/GPIO43)
/J3_3: J3.3, U3.J3_3 (U0RXD/GPIO44)
/J3_9: J3.9, R2.1, U1.26 (NFAULT/IN1), U2.26 (NFAULT/IN1), U3.J3_9 (MTCK/GPIO39)
/J3_11: J3.11, U3.J3_11 (GPIO37)
/J3_12: J3.12, U3.J3_12 (GPIO36)
/J3_13: J3.13, U3.J3_13 (GPIO35)
/J3_14: J3.14, U3.J3_14 (GPIO0)
/J3_15: J3.15, U3.J3_15 (GPIO45)
/J3_16: J3.16, U3.J3_16 (GPIO48), U16.6 (S)
/J3_17: J3.17, U3.J3_17 (GPIO47)
/J3_19: J3.19, U3.J3_19 (USB_D+/GPIO20)
/J3_20: J3.20, U3.J3_20 (USB_D-/GPIO19)
/U1_IN2: U1.40 (IN2/OCPM), U13.4 (Y)
/U1_IN4: U1.38 (RSVD/MODE2), U14.4 (Y)
/U1_OUT1: R17.2, U1.4 (OUT1), U1.5 (OUT1), U1.6 (OUT1), U6.8 (IN+)
/U1_OUT2: CN2.2, U1.7 (OUT2), U1.8 (OUT2), U1.9 (OUT2)
/U1_OUT3: R18.2, U1.17 (OUT1), U1.18 (OUT1), U1.19 (OUT1), U7.8 (IN+)
/U1_OUT4: CN3.1, U1.14 (OUT2), U1.15 (OUT2), U1.16 (OUT2)
/U2_IN2: U2.40 (IN2/OCPM), U15.4 (Y)
/U2_IN4: U2.38 (RSVD/MODE2), U16.4 (Y)
/U2_OUT1: R19.2, U2.4 (OUT1), U2.5 (OUT1), U2.6 (OUT1), U10.8 (IN+)
/U2_OUT2: CN4.2, U2.7 (OUT2), U2.8 (OUT2), U2.9 (OUT2)
/U2_OUT3: R20.2, U2.17 (OUT1), U2.18 (OUT1), U2.19 (OUT1), U11.8 (IN+)
/U2_OUT4: CN5.1, U2.14 (OUT2), U2.15 (OUT2), U2.16 (OUT2)
/nSLEEP: R1.1, U1.42 (NSLEEP/VCC), U2.42 (NSLEEP/VCC)
/pure5V: C11.1, C17.1, D14.2 (A), U5.7 (EN), U5.8 (VCC), U8.3 (+VO)
GND: C1.2, C2.2, C5.2, C6.2, C9.2, C10.2, C11.2, C12.1, C13.1, C14.2, C15.2, C16.2, C17.2, C18.2, C19.2, C20.2, C21.2, C22.2, C23.2, CN1.2, CN6.2, D6.1 (K), D7.1 (K), D8.1 (K), D9.1 (K), D13.2 (A2), J1.22, J3.1, J3.21, J3.22, R3.2, R4.2, R5.2, R6.2, R8.1, R9.2, U1.3 (PGND), U1.10 (PGND), U1.13 (PGND), U1.20 (PGND), U1.22 (GND/VCP), U1.23 (GND/CPH), U1.27 (OCPM/IN2), U1.28 (MODE1/RSVD), U1.37 (DECAY/IPROPI), U1.EPAD, U2.3 (PGND), U2.10 (PGND), U2.13 (PGND), U2.20 (PGND), U2.22 (GND/VCP), U2.23 (GND/CPH), U2.27 (OCPM/IN2), U2.28 (MODE1/RSVD), U2.37 (DECAY/IPROPI), U2.EPAD, U3.J1_22 (GND), U3.J3_1 (GND), U3.J3_21 (GND), U3.J3_22 (GND), U4.4 (~LDAC), U4.10 (VSS), U5.5 (GND), U6.2 (GND), U6.3 (REF2), U6.7 (REF1), U7.2 (GND), U7.3 (REF2), U7.7 (REF1), U8.2 (GND), U9.2 (CAT), U9.4 (CAT), U9.6 (CAT), U9.8 (CAT), U9.9 (EM), U9.11 (EM), U9.13 (EM), U9.15 (EM), U10.2 (GND), U10.3 (REF2), U10.7 (REF1), U11.2 (GND), U11.3 (REF2), U11.7 (REF1), U12.12 (V-), U13.2 (GND), U14.2 (GND), U15.2 (GND), U16.2 (GND)
unnamed: CN9.1, R12.1
unnamed: CN9.2, R13.1
unnamed: CN9.3, R15.1
unnamed: CN9.4, R16.1
unnamed: D1.2 (A), D10.1 (K)
unnamed: D1.1 (K), R11.1
unnamed: D2.2 (A), R12.2
unnamed: D2.1 (K), U9.1 (AN)
unnamed: D3.2 (A), R13.2
unnamed: D3.1 (K), U9.3 (AN)
unnamed: D4.2 (A), R15.2
unnamed: D4.1 (K), U9.5 (AN)
unnamed: D5.2 (A), R16.2
unnamed: D5.1 (K), U9.7 (AN)
unnamed: D6.2 (A), RN1.1 (R1.1)
unnamed: D7.2 (A), RN1.2 (R2.1)
unnamed: D8.2 (A), RN1.3 (R3.1)
unnamed: D9.2 (A), RN1.4 (R4.1)
unnamed: CN7.1, D10.2 (A)
unnamed: CN6.1, D11.2 (A)
unnamed: C16.1, D11.1 (K), U8.1 (VIN)
unnamed: D12.2 (A), Q1.1 (G), R7.1, R8.2
unnamed: D15.1 (K), R9.1
unnamed: CN1.1, Q1.2 (D)
unnamed: C4.1, U1.44 (CPH/GND)
unnamed: C4.2, U1.43 (CPL/DVDD)
unnamed: C5.1, U1.24 (DVDD/CPL)
unnamed: R3.1, U1.30 (IPROPI/DECAY)
unnamed: R4.1, U1.31 (IPROPI/RSVD)
unnamed: C3.2, U1.1 (VCP/GND)
unnamed: C8.1, U2.44 (CPH/GND)
unnamed: C8.2, U2.43 (CPL/DVDD)
unnamed: C9.1, U2.24 (DVDD/CPL)
unnamed: R5.1, U2.30 (IPROPI/DECAY)
unnamed: R6.1, U2.31 (IPROPI/RSVD)
unnamed: C7.2, U2.1 (VCP/GND)
unnamed: R11.2, U5.2 (A)
unnamed: CN7.2, U5.3 (C)
unnamed: CN2.1, R17.1, U6.1 (IN-)
unnamed: CN3.2, R18.1, U7.1 (IN-)
unnamed: CN4.1, R19.1, U10.1 (IN-)
unnamed: CN5.2, R20.1, U11.1 (IN-)
unnamed: U4.6 (VOUTA), U12.4 (-)
unnamed: U4.7 (VOUTB), U12.6 (-)
unnamed: U4.8 (VOUTC), U12.10 (-)
unnamed: U4.9 (VOUTD), U12.8 (-)

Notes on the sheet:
48V power
Inputs
reverse protection
how to add easyeda parts : easyeda2kicad --full --lcsc_id=(for example)C475222 it will add it to /home/orkiman/Documents/Kicad/easyeda2kicad/
24v to 5v
current sense
5v input
protection tvs

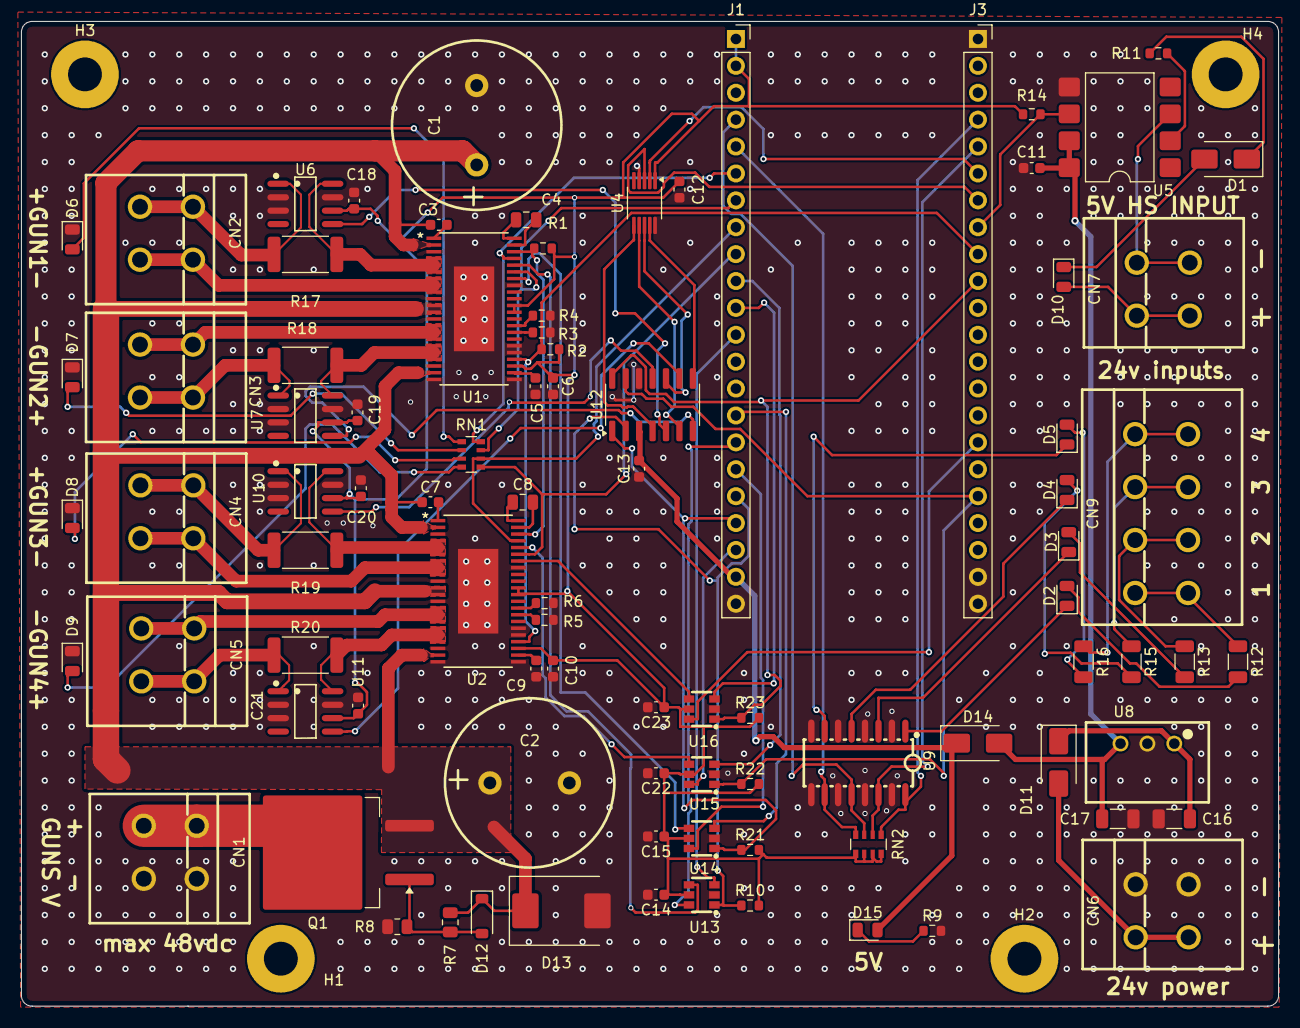
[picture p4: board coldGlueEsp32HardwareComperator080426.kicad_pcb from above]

Board: 2 copper layers, 118.7 x 93.0 mm, 93 parts (0 on the bottom side), 92 nets.

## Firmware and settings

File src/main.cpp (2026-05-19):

#include <Arduino.h>

#include "config/Config.h"
#include "comms/Events.h"
#include "comms/UartJson.h"
#include "hw/Driver.h"
#include "hw/Dac.h"
#include "hw/Encoder.h"
#include "rt/GunSequencer.h"
#include "rt/PatternScheduler.h"
#include "rt/TestRunner.h"
#include "sys/Fault.h"
#include "sys/Watchdog.h"
#include "sys/Status.h"

// =============================================================================
// Cold Glue Controller - Main Controller firmware entry point.
//
// Core 0 (Management / Comms):
//   uart_rx   prio 4    NDJSON parser + dispatcher
//   evt_emit  prio 5    Drains evt:: queue -> Serial
//   wdog      prio 3    HMI link watchdog
//   status    prio 2    5 Hz status events
//
// Core 1 (Real-Time Hardware):
//   pattern   prio 7    Encoder poll + fire pattern events
//   dac       prio 6    MCP4728 I2C writer
//   <ISRs>    IRAM      Peak (per gun) + photocell + nFAULT + PCNT overflow
// =============================================================================

void setup() {
    // ---- 1. Config defaults (both buffers seeded) ----
    cfg::Config::init();

    // ---- 2. Safe-state every output BEFORE anything else can fire ----
    drv::init();

    // ---- 3. Comms backbone: Serial + event emitter + RX/JSON ----
    evt::init();
    uartjson::init();

    // ---- 4. HW peripherals ----
    dac::init();          // I2C + DacTask (Core 1)
    encoder::init();      // PCNT + photocell ISR (any-edge)
    fault::init();        // nFAULT ISR

    // ---- 5. RT layer ----
    seq::init();          // peak ISRs + hold timers
    pattern::init();      // PatternTask (Core 1)
    testrun::init();      // diagnostic test runner

    // ---- 6. Supervisors ----
    watchdog::init();
    status::init();

    // ---- 7. Announce readiness to HMI ----
    evt::postReady();
}

void loop() {
    // Everything runs in FreeRTOS tasks.  The Arduino loopTask sits idle.
    vTaskDelay(pdMS_TO_TICKS(1000));
}

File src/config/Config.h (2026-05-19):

#pragma once
#include <Arduino.h>
#include <atomic>
#include "hw/Pins.h"

// =============================================================================
// Config & Pattern storage with lock-free, double-buffered publication.
//
// Hot path (Core 1) reads via Config::active() returning a const* snapshot.
// Cold path (Core 0 / JSON task) builds the next snapshot in the inactive
// buffer then publishes with Config::publish().
//
// Patterns are stored inline inside RuntimeConfig so a single pointer swap
// publishes config + patterns atomically.
// =============================================================================

namespace cfg {

constexpr size_t MAX_PATTERN_ELEMENTS_PER_GUN = 64;

struct PatternElement {
    float    start_mm;
    float    end_mm;
    float    spacing_mm;   // 0 -> line, >0 -> dots
};

enum class PatternType : uint8_t { None = 0, Lines = 1, Dots = 2 };

struct GunPattern {
    PatternType    type         = PatternType::None;
    uint8_t        count        = 0;
    // Total on-time budget for one fire cycle (ms), measured from the moment
    // seq::fire() is called -- i.e. from the start of the Peak phase, NOT
    // from the LM339 peak-current trip. When this elapses the sequencer is
    // forced into Phase 3 (Active Fast Decay) regardless of which phase it
    // is currently in. This also serves as the fail-safe if peak current
    // is never reached (open coil, broken sense path, etc.).
    //   * Dots mode  -> droplet on-time (the user-facing "drop size").
    //   * Lines mode -> ignored for normal pattern execution (lines end on
    //                   encoder position via seq::abort). Still acts as the
    //                   global 5 s safety ceiling enforced inside fire().
    float          on_timeout_ms = 1.2f;
    PatternElement elems[MAX_PATTERN_ELEMENTS_PER_GUN];
};

struct RuntimeConfig {
    // ---- set_config payload (global) ----
    float    pulses_per_mm        = 12.34f;
    float    min_speed_mm_s       = 100.0f;
    float    photocell_offset_mm  = 250.0f;
    uint32_t debounce_ms          = 20;
    float    pick_current_a       = 1.0f;
    float    hold_current_a       = 0.4f;

    // ---- per-gun pattern (includes per-gun on_timeout_ms / droplet size) ----
    GunPattern pattern[pins::NUM_GUNS];
};

class Config {
public:
    static void init();                          // populates defaults in both buffers
    static const RuntimeConfig* active();        // hot-path read (IRAM-safe)
    static RuntimeConfig*       editScratch();   // cold-path write target
    static void publish();                       // atomic swap of active pointer

private:
    static RuntimeConfig             buf_[2];
    static std::atomic<uint8_t>      activeIdx_;
};

// ---- Runtime/system state (separate from config) ----
struct SystemState {
    std::atomic<bool>     active{false};        // mirrors HMI set_active command
    std::atomic<bool>     fault{false};         // nFAULT latched
    std::atomic<uint32_t> lastCmdMs{0};         // watchdog refresh timestamp
};

extern SystemState g_sys;

} // namespace cfg

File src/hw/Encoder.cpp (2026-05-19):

#include "Encoder.h"
#include "Pins.h"
#include "config/Config.h"

#include <driver/pcnt.h>
#include <driver/gpio.h>
#include <esp_timer.h>

// Forward decls from pattern scheduler (Core 1).
namespace pattern {
    void onPhotocellEdge       (uint32_t pulseCountAtEdge) IRAM_ATTR;
    void onPhotocellFallingEdge(uint32_t pulseCountAtEdge) IRAM_ATTR;
}

namespace encoder {

static constexpr pcnt_unit_t PCNT_UNIT = PCNT_UNIT_0;
static constexpr int16_t     PCNT_LIMIT = 30000;          // wrap window

// 32-bit accumulator extending PCNT's 16-bit counter.
static volatile uint32_t s_pulseAccum = 0;
static volatile int16_t  s_lastSnap   = 0;

// Debounce state for photocell.
static volatile int64_t s_lastEdgeUs = 0;

static void IRAM_ATTR pcntOverflowIsr(void* /*arg*/) {
    uint32_t status = 0;
    pcnt_get_event_status(PCNT_UNIT, &status);
    if (status & PCNT_EVT_H_LIM) {
        s_pulseAccum += (uint32_t)PCNT_LIMIT;
        pcnt_counter_clear(PCNT_UNIT);
        s_lastSnap = 0;
    }
}

uint32_t IRAM_ATTR pulseCount() {
    int16_t cnt = 0;
    pcnt_get_counter_value(PCNT_UNIT, &cnt);
    return s_pulseAccum + (uint32_t)(uint16_t)cnt;
}

static void IRAM_ATTR photocellIsr(void* /*arg*/) {
    int64_t  now        = esp_timer_get_time();
    uint32_t debounceUs = cfg::Config::active()->debounce_ms * 1000u;
    if ((uint64_t)(now - s_lastEdgeUs) < debounceUs) return;
    s_lastEdgeUs = now;

    uint32_t p     = pulseCount();
    int      level = gpio_get_level((gpio_num_t)pins::PHOTOCELL);
    if (level) pattern::onPhotocellEdge(p);
    else       pattern::onPhotocellFallingEdge(p);
}

static void initPcnt() {
    pcnt_config_t c = {};
    c.pulse_gpio_num = pins::ENCODER;
    c.ctrl_gpio_num  = PCNT_PIN_NOT_USED;
    c.lctrl_mode     = PCNT_MODE_KEEP;
    c.hctrl_mode     = PCNT_MODE_KEEP;
    c.pos_mode       = PCNT_COUNT_INC;        // count rising edges
    c.neg_mode       = PCNT_COUNT_DIS;
    c.counter_h_lim  = PCNT_LIMIT;
    c.counter_l_lim  = -1;
    c.unit           = PCNT_UNIT;
    c.channel        = PCNT_CHANNEL_0;
    pcnt_unit_config(&c);

    // ~80 MHz APB / 1023 ticks ~= 12.8 us min pulse width filter.  Plenty for
    // an industrial encoder; tightens if needed via cfg later.
    pcnt_set_filter_value(PCNT_UNIT, 100);
    pcnt_filter_enable(PCNT_UNIT);

    pcnt_event_enable(PCNT_UNIT, PCNT_EVT_H_LIM);
    pcnt_counter_pause(PCNT_UNIT);
    pcnt_counter_clear(PCNT_UNIT);

    pcnt_isr_service_install(0);
    pcnt_isr_handler_add(PCNT_UNIT, pcntOverflowIsr, nullptr);
    pcnt_counter_resume(PCNT_UNIT);
}

static void initPhotocell() {
    gpio_config_t g = {};
    g.pin_bit_mask = (1ULL << pins::PHOTOCELL);
    g.mode         = GPIO_MODE_INPUT;
    g.pull_up_en   = GPIO_PULLUP_DISABLE;     // opto provides defined level
    g.pull_down_en = GPIO_PULLDOWN_DISABLE;
    g.intr_type    = GPIO_INTR_ANYEDGE;       // both edges; level decides
    gpio_config(&g);

    // gpio_install_isr_service is idempotent-ish: ESP_ERR_INVALID_STATE if
    // already installed (e.g. by Arduino attachInterrupt).  Ignore that.
    gpio_install_isr_service(ESP_INTR_FLAG_IRAM);
    gpio_isr_handler_add((gpio_num_t)pins::PHOTOCELL, photocellIsr, nullptr);
}

void init() {
    initPcnt();
    initPhotocell();
}

void injectSwTrigger() {
    pattern::onPhotocellEdge(pulseCount());
}

} // namespace encoder

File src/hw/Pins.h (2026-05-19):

#pragma once
#include <stdint.h>

// =============================================================================
// Cold Glue Controller - ESP32-S3 Pin Map
// Source of truth: docs/initial prompt.md  Section 4
// =============================================================================

namespace pins {

constexpr uint8_t NUM_GUNS = 4;

// Per-gun pin arrays, indexed 0..3 (Gun 1..Gun 4).
constexpr int8_t OPTO_IN[NUM_GUNS]    = { 1,  2,  4,  5  }; // 24V opto inputs (Gun1 = photocell)
constexpr int8_t DRV_IN1[NUM_GUNS]    = { 6,  7, 15, 16  }; // DRV8262 IN1/IN3 main drive
constexpr int8_t MUX_IN2[NUM_GUNS]    = { 8,  9, 17, 18  }; // MUX I0 input (manual ESP32 override)
constexpr int8_t MUX_SELECT[NUM_GUNS] = {10, 11, 14, 48  }; // S=1 LM339 control, S=0 ESP32 control
constexpr int8_t PEAK_IRQ[NUM_GUNS]   = {12, 13, 21, 38  }; // From LM339, ext 10k pull-up

// Photocell trigger is Opto Input #1 by spec ("e.g. Input_1_24v").
constexpr int8_t PHOTOCELL = OPTO_IN[0];

// --- Global pins ---
constexpr int8_t I2C_SDA  = 41;   // -> MCP4728
constexpr int8_t I2C_SCL  = 42;   // -> MCP4728
constexpr int8_t N_FAULT  = 39;   // DRV8262 nFAULT, active LOW, ext 10k pull-up
constexpr int8_t ENCODER  = 40;   // 6N137 single-channel pulse input

// --- UART0 (HMI link via CP2102 / pin header) ---
// Default Arduino Serial uses these on ESP32-S3 DevKitC-1.
constexpr int8_t UART_TX  = 43;
constexpr int8_t UART_RX  = 44;

} // namespace pins

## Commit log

2026-04-08 Initial commit: Forked to new hardware-assist design
    [DDW0044E.stp, DRV8262DDWR.step, coldGlueEsp32HardwareComperator080426.kicad_pcb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]
2026-04-09 complete adding hardware comerator to schematics
    [coldGlueEsp32HardwareComperator080426.kicad_sch]
2026-04-12 wiring headers and remove esp from board before routing
    [coldGlueEsp32HardwareComperator080426.kicad_pcb, coldGlueEsp32HardwareComperator080426.kicad_sch, freerouting.dsn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]
2026-04-13 CN3,5 fix orientation(before freerouting)
    [coldGlueEsp32HardwareComperator080426.kicad_pcb, coldGlueEsp32HardwareComperator080426.kicad_sch]
2026-04-14 complete routing
    [coldGlueEsp32HardwareComperator080426.kicad_pcb, coldGlueEsp32HardwareComperator080426.kicad_sch]
2026-04-18 routed no errors
    [coldGlueEsp32HardwareComperator080426.kicad_pcb, freerouting.dsn, temp-freerouting.dsn]
2026-04-19 all lcsc part numbers collected
    [coldGlueEsp32HardwareComperator080426.kicad_pcb, coldGlueEsp32HardwareComperator080426.kicad_sch]
2026-04-21 thickened some 48 traces so i can use 1oz copper thickness safely
    [coldGlueEsp32HardwareComperator080426.kicad_pcb]
2026-04-21 lcsc collumn renamed all parts in stock now
    [coldGlueEsp32HardwareComperator080426.kicad_pcb, coldGlueEsp32HardwareComperator080426.kicad_sch]
2026-05-10 Clean up: Move remaining KiCad files and libraries to hardware directory
    [DDW0044E.stp, DRV8262DDWR.step, bom.csv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]
2026-05-19 Stage 1: Complete main controller firmware scaffold
    - PlatformIO project for ESP32-S3-WROOM-1-N16R8 (16MB Flash / 8MB PSRAM)
    - Dual-core FreeRTOS architecture:
    - Core 1: Real-time pattern scheduler, gun sequencers, ISRs
    - Core 0: NDJSON UART comms, watchdog, status emitter
    - Hardware abstraction: DRV8262 driver, MCP4728 DAC (queued I2C), PCNT encoder
    - Per-gun dot sequence: Peak current → hardware-chopped Hold → Active Fast Decay
    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
2026-05-19 docs: record Stage 2 GUI progress and per-gun on_timeout_ms landing
    - Stage 2 status updated to "In progress" — PySide6 GUI scaffold in gui/
    tree; mock-link works, real serial path implemented.
    - Per-gun `on_timeout_ms` replaces global `hold_time_ms`:
    - Moved from RuntimeConfig to GunPattern; semantics changed from
    "Hold-phase duration started by peakIsr" to "total Peak+Hold budget
    started by fire()".
    - Default 1.2 ms; set via optional `on_timeout_ms` field in set_pattern.
    - Dots mode: user-facing
    [Config.h, GunSequencer.cpp, PatternScheduler.cpp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]
